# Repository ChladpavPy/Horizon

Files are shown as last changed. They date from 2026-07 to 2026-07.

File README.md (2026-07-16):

# Horizon
Custom Rocket Flight Controller

So first I want to explain, why I started this project. I have always wanted to build my own rocket, but for a long time it was just impossible and senseless. It is generally prohibited to fly with your own custom rockets, there was nowhere to safely test them, and it could be very dangerous. But then I noticed the ČVUT rocketry challenge, where it is actually possible to do it safely and legally.

I also thought about getting some friends or classmates to join this project, which is very likely to happen. We would probably work on the mechanical rocket body together, but I realized that a rocket without a computer is basically just a firework. So it was my idea to design and build my own custom flight computer for this rocket. I also designed the avionics bay to house the electronics.

I am still not exactly sure what the real specifications for this competition will be, because they will probably be published next year in February. But that is actually a big advantage. It means I will have plenty of time to test the flight computer thoroughly and gather a solid team to build the rest of the project. I already did all the hardware and computer work, so we are prepared to fly it.

You might notice that parts like the rocket engine, the main body tube, and the deployable parachute are not included in the bom. The parachute will be deployed by the pyro channels that I designed on the board, but these mechanical parts are missing from the BOM because they will very likely be funded and specified by the ČVUT competition with the proper dimensions. For the avionics bay, it does not really matter what the final dimensions are. Because it is just plastic, I can easily redesign it for different tube dimensions and 3D print it again.

## Project Features

* **Microcontroller:** STM32F405RGT6 (64-pin, 32-bit ARM Cortex-M4)
* **Stackup:** 4-Layer PCB for internal routing and better EMI shielding during flight
* **Sensors:** ICM-42688-P 6-axis IMU, ADXL372 high-g (200g) accelerometer for launch and impact detection, and dual barometers (BMP580 & MS5611) for precise altitude tracking
* **Telemetry:** LoRa E22-900M22S module for long-range real-time data transmission
* **Power:** 2S LiPo main input with high-efficiency TPS54525 step-down regulator
* **Data Logging:** Onboard W25Q128 128Mbit SPI Flash memory for high-speed flight data recording
* **Recovery System:** Dedicated pyro channels designed for reliable parachute deployment
* **Positioning:** Interface for high-precision external GPS (GEPRC GEP-M1025-DQ)

* And more other...

## Gallery

### 3D PCB Render
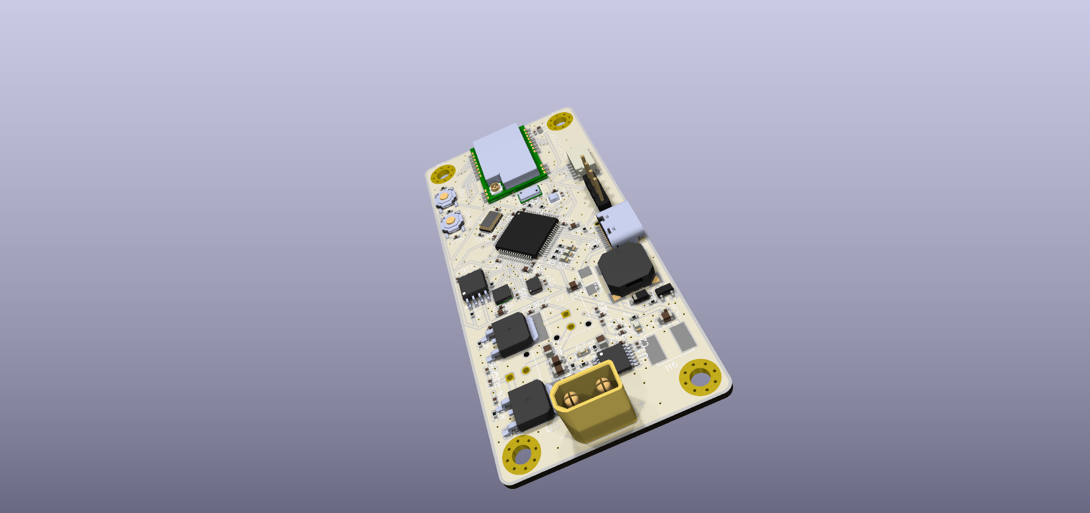
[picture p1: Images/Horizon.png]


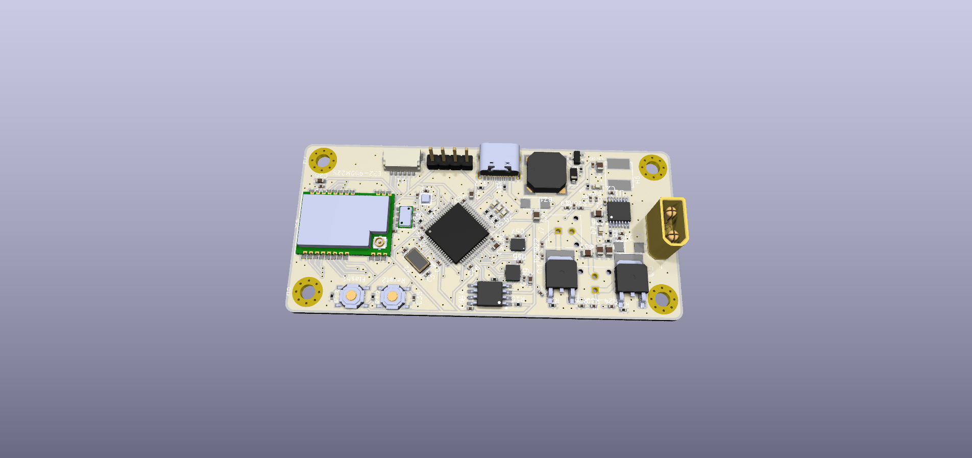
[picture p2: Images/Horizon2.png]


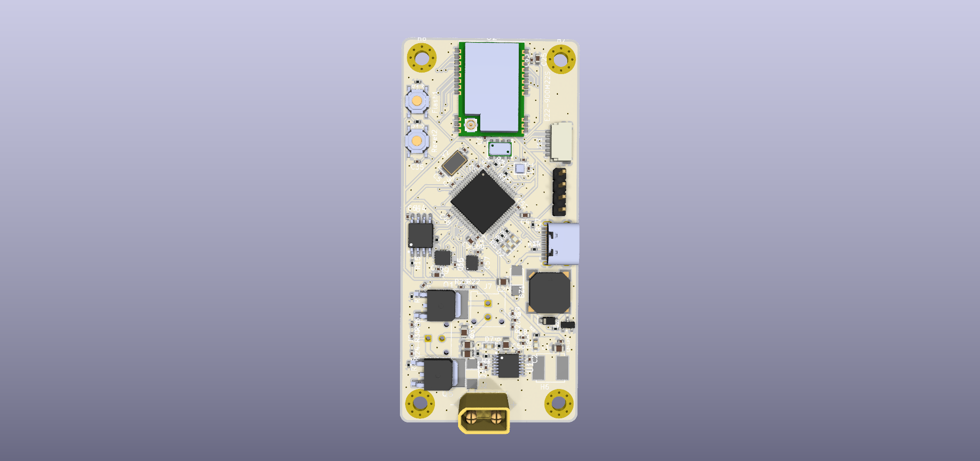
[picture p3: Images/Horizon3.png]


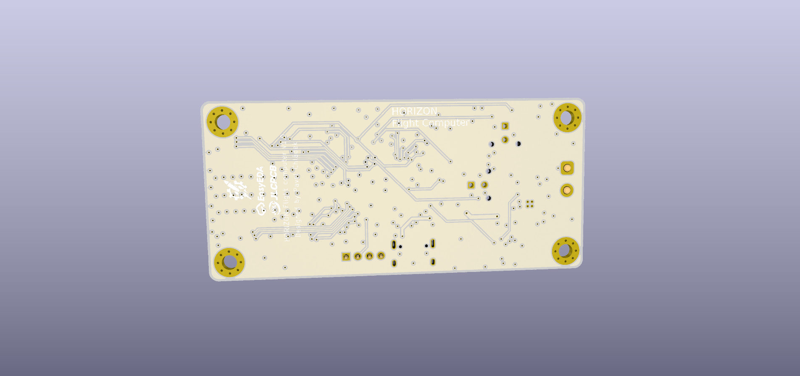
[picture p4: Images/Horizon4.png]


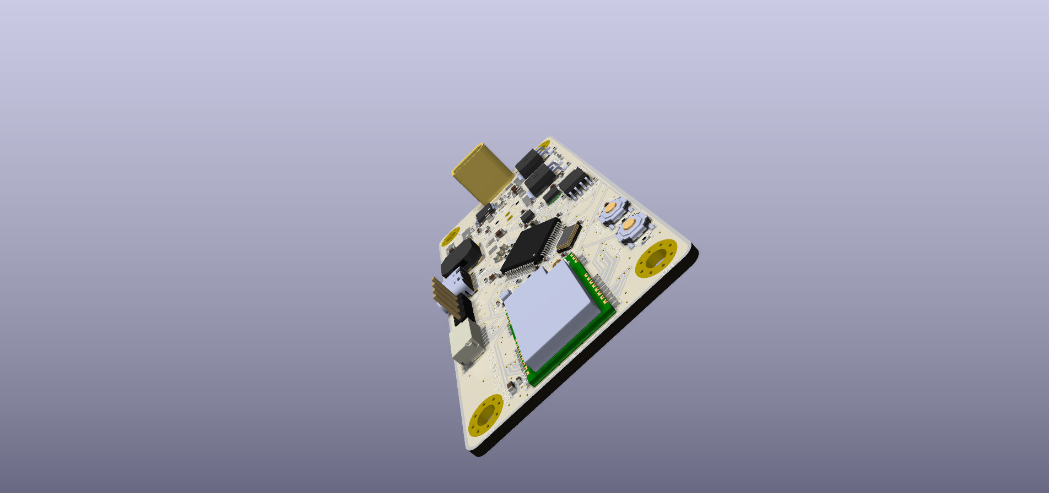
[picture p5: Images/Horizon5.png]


### PCB Routing
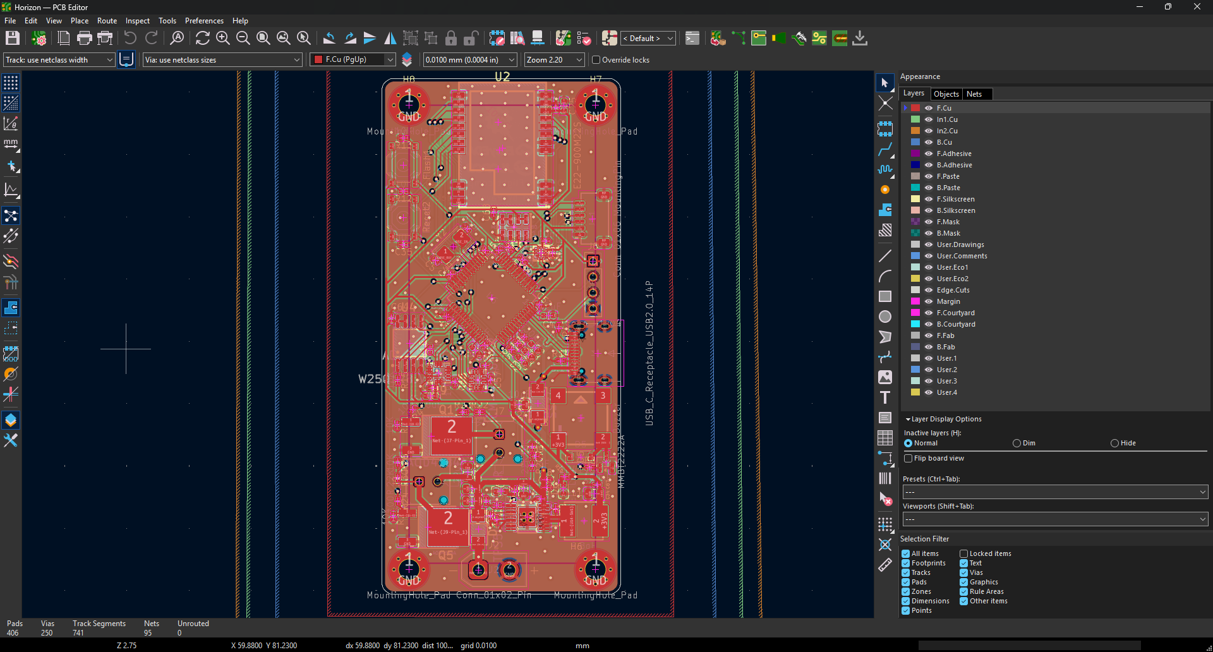
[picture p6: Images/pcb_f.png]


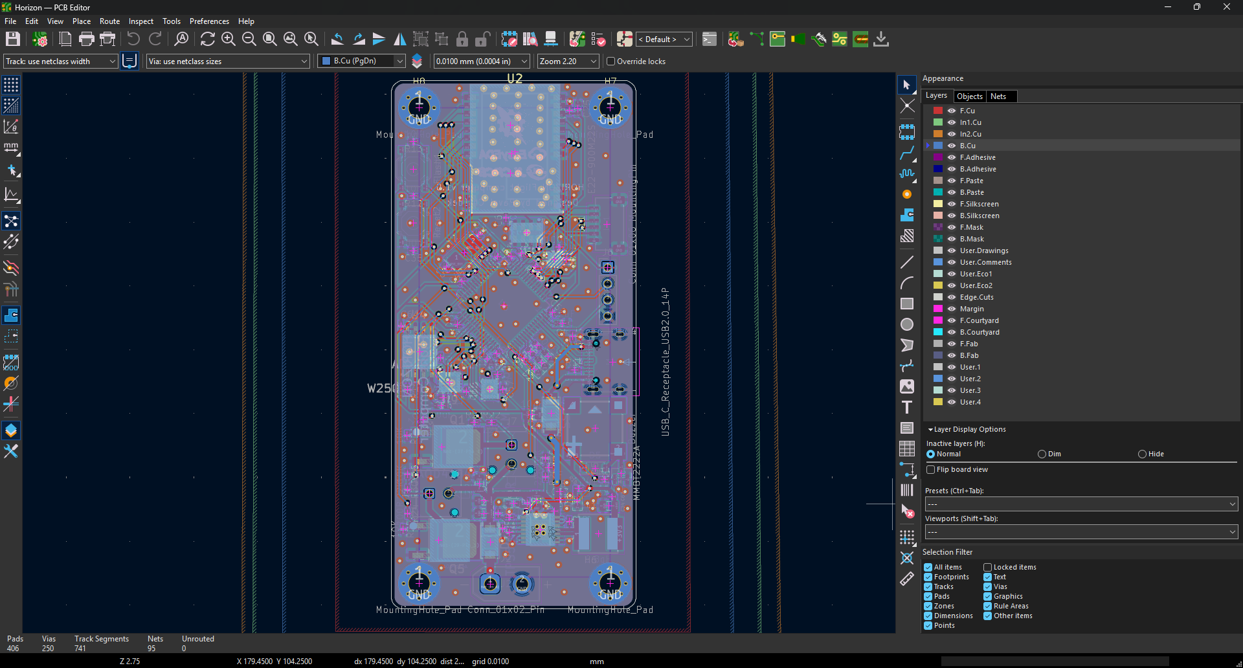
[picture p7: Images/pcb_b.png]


### Schematic
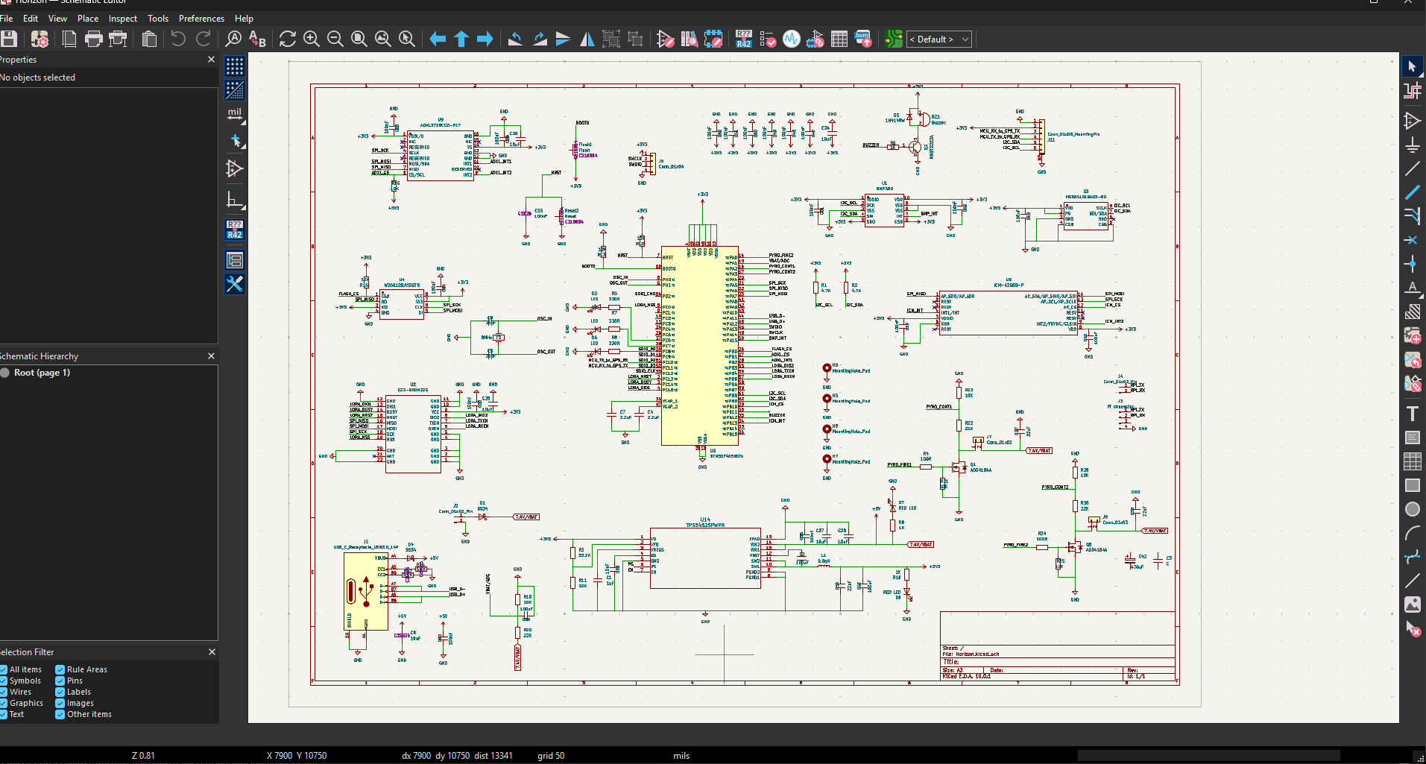
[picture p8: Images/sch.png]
Schematic


### Avionics Bay Assembly

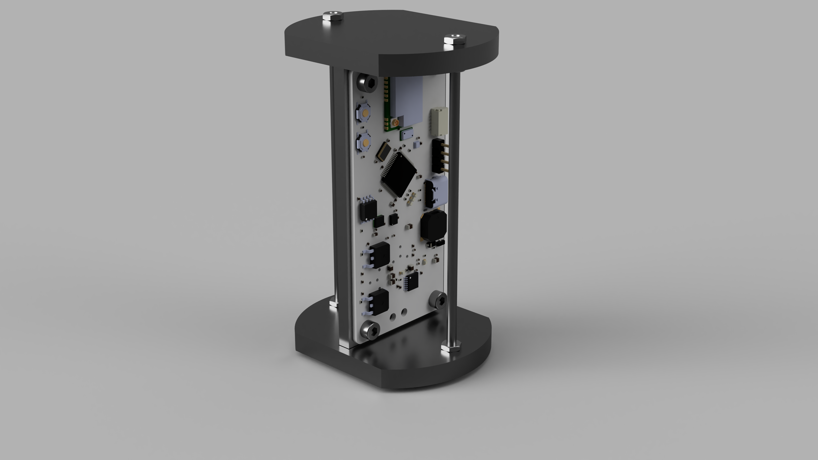
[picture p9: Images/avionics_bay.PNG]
Avionics Bay


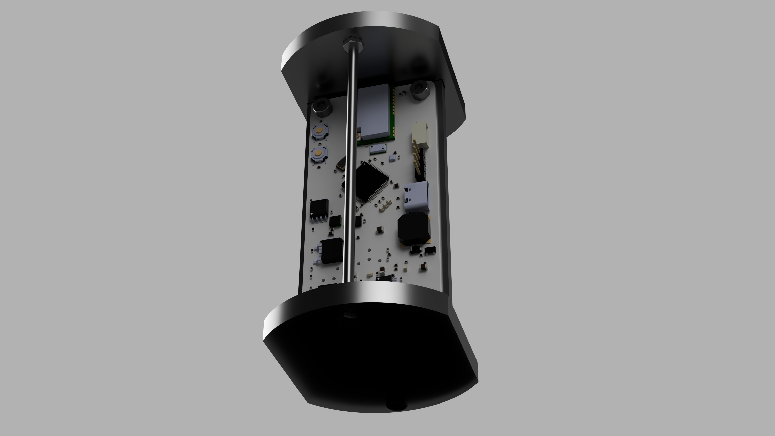
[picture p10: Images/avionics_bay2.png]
Avionics Bay


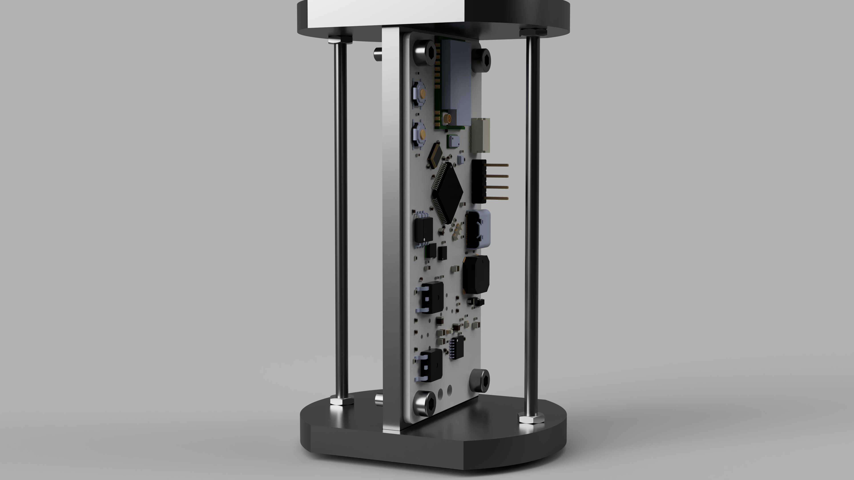
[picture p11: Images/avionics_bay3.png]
Avionics Bay


---

## Bill of Materials (BOM)

| Component | Qty | Purpose / Description | Price (USD) | Link / Distributor |
| :--- | :---: | :--- | :--- | :--- |
| **Custom PCB Manufacture** | 2 | The actual circuit board to solder everything on. Ordered via JLCPCB standard 4-layer service. | 209.53$ | [JLCPCB](https://jlcpcb.com) |
| **2S battery** | 1 | Power source / The whole pcb and pyros will get power from this. | 12.77$ | [Allegro](https://allegro.cz/produkt/akumulator-lipo-tattu-hv-550mah-2s-7-6v-xt30-dac8961b-6a7f-4425-9fd0-e271a79d3002?offerId=17837986320) |
| **HOTA D6 Pro Charger** | 1 | Dual-channel AC/DC LiPo charger for safe battery maintenance. Critical for preventing thermal runaway during 2S LiPo charging. Specifically chosen for its ability to accurately measure internal cell resistance (IR) to verify battery health for high-current pyro deployments, and its adjustable lab power supply mode for safely bringing up and testing the custom TPS step-down converters on the PCB without the risk of frying the new board. | $121.57 | [HobbyDrone.cz](https://www.hobbydrone.cz/cs/charger-hota-d6-pro-325w-15a-1-6s-dual-ac-dc/) |
| **GEPRC GEP-M1025-DQ GPS** | 1 | High-precision positioning data (u-blox M10) with integrated QMC5883L compass and backup DPS310 barometer. | $19.80 | [Banggood](https://www.banggood.com/cs/GEPRC-GEP-M1025-Series-M10-Chip-GPS-Module-for-RC-Drone-FPV-Racing-Helicopter-Quadcopter-RC-Airplane-Car-p-2000868.html?ID=6324596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) |

### Manual Assembly Components (LCSC.com)
*Note: Due to the high complexity and cost of standard PCBA services for LGA-type sensors, these components are ordered separately and will be manually reflow soldered using a stencil and hot plate.*

| Component | Qty | Purpose / Description | Price (USD) | LCSC Part # |
| :--- | :---: | :--- | :--- | :--- |
| **ADXL372BCCZ-RL7** | 2 | High-g accelerometer (200g) for impact detection. | 35.41$ | C579465 |
| **BMP580** | 5 | Precision barometric pressure sensor. | 5.96$ | C22391138 |
| **TPS54525PWPR** | 5 | High-efficiency buck regulator. | 5.24$ | C140350 |
| **Total LCSC Cost** | - | Including shipping | **50.46$** | - |

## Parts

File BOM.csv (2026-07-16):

Designator | Footprint | Quantity | Value | LCSC Part #
BZ1 | BUZ-SMD_4P-L8.5-W8.5-P8.50-TL | 1 | Buzzer | C95298
C1 | 0402 | 1 | 1uF | C52923
C2, C47, C48, C49, C50, C51, C52, C53, C56, C57, C59, C60, C61, C62, C63, C64, C65, C66, C67, C68 | 0402 | 20 | 100nF | C307331
C24, C27, C28 | 0805 | 3 | 10uF | C15850
C25, C26 | 0603 | 2 | 10uF | C19702
C34, C36, C37 | 0805 | 3 | 22uF | C45783
C35 | 0402 | 1 | 100nF | C1525
C4, C7 | 0603 | 2 | 2.2uF | C23630
C5, C6 | 0402 | 2 | 33pF | C1562
C58 | 0402 | 1 | 10nF | C15195
C8 | 0603 | 1 | 10uF | C96446
D1, D4 | SMA_L4.3-W2.6-LS5.2-RD | 2 | SS34 | C8678
D2, D7, D8 | 0603 | 3 | LED | C2286
D3 | 0603 | 1 | LED | C2288
D5 | D_SOD-123 | 1 | 1N4148W | C81598
D6 | 0603 | 1 | LED | C12624
FLASH1 | SW_Push_1P1T_XKB_TS-1187A | 1 | Flash | C318884
J1 | USB_C_Receptacle_HCTL_HC-TYPE-C-16P-01A | 1 | USB_C_Receptacle_USB2.0_14P | C19274016
J11 | JST_SH_SM06B-SRSS-TB_1x06-1MP_P1.00mm_Horizontal | 1 | Conn_01x06_MountingPin
J2 | AMASS_XT30UPB-M_1x02_P5.0mm_Vertical | 1 | Conn_01x02_Pin | C428721
J6 | PinHeader_1x04_P2.54mm_Vertical | 1 | Conn_01x04
J7, J9 | Molex_Micro-Fit_3.0_43045-0212_2x01_P3.00mm_Vertical | 2 | Conn_01x02
L1 | IND-SMD_L6.0-W6.0_SWPA6045S | 1 | 6.8qH | C57254
Q1, Q5 | TO-252-2_L6.6-W6.1-P4.57-LS9.9-TL-CW | 2 | AOD4184A | C99124
Q2 | SOT-23 | 1 | MMBT2222A | C8512
R1, R2 | 0402 | 2 | 4.7K | C25900
R10, R6, R9 | 0402 | 3 | 1K | C11702
R11, R25 | 0402 | 2 | 10K | C25804
R12, R13, R15, R16, R19, R21, R23, R26 | 0402 | 8 | 10K | C25744
R14, R17 | 0402 | 2 | 5.1K | C25905
R20, R22, R30 | 0402 | 3 | 22K | C25768
R24, R4 | 0402 | 2 | 100R | C25076
R3 | 0402 | 1 | 33.2K | C850963
R5, R7, R8 | 0402 | 3 | 330R | C25104
RESET2 | SW_Push_1P1T_XKB_TS-1187A | 1 | Reset | C318884
U1 | LGA-10_L2.0-W2.0-P0.50-TL_BMP580 | 1 | BMP580 | C22391138
U14 | TSSOP-14_L5.0-W4.4-P0.65-LS6.4-BL-EP | 1 | TPS54525PWPR | C140350
U2 | WIRELM-SMD_E22-900M22S | 1 | E22-900M22S | C411293
U3 | SENSORS-SMD_MS5611-01BA03 | 1 | MS561101BA03-50
U4 | SOIC-8_L5.3-W5.3-P1.27-LS8.0-BL | 1 | W25Q128JVSIQTR | C97521
U5 | LGA-14_L3.0-W2.5-P0.50-TL | 1 | ICM-42688-P | C1850418
U6 | LQFP-64_10x10mm_P0.5mm | 1 | STM32F405RGTx | C15742
U9 | LGA-16_L3.3-W3.0-P0.50-TL | 1 | ADXL372BCCZ-RL7 | C579465
Y2 | Crystal_SMD_5032-2Pin_5.0x3.2mm | 1 | 8MHz | C115962

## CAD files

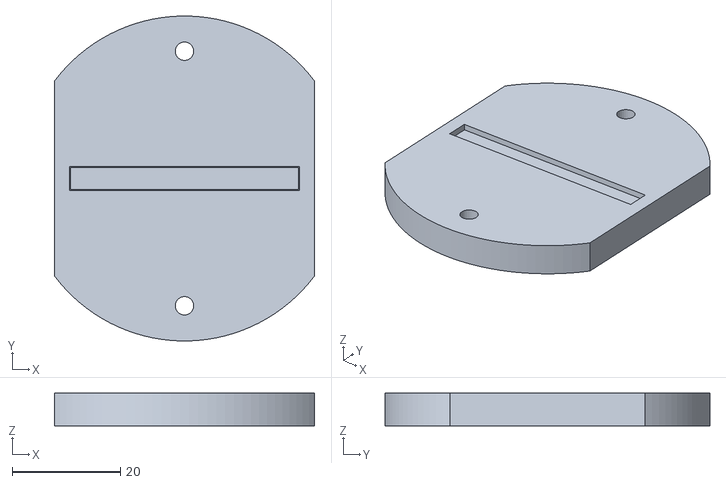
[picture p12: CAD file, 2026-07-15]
3D_Models/Bottom_Avionics_Bay.stl
48.0 x 60.0 x 6.00

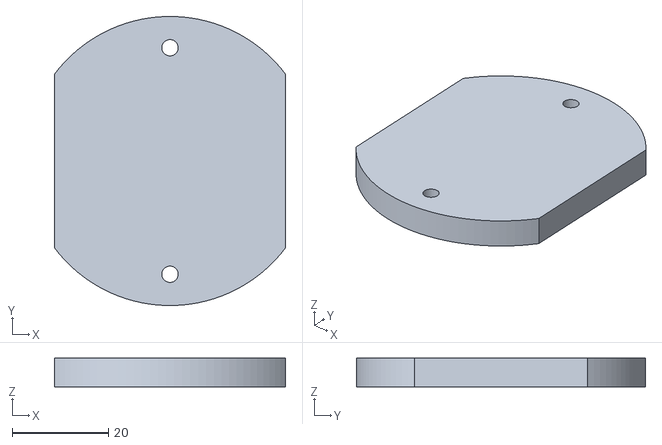
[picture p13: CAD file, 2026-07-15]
3D_Models/Upper_Avionics_Bay.stl
48.0 x 60.0 x 6.00

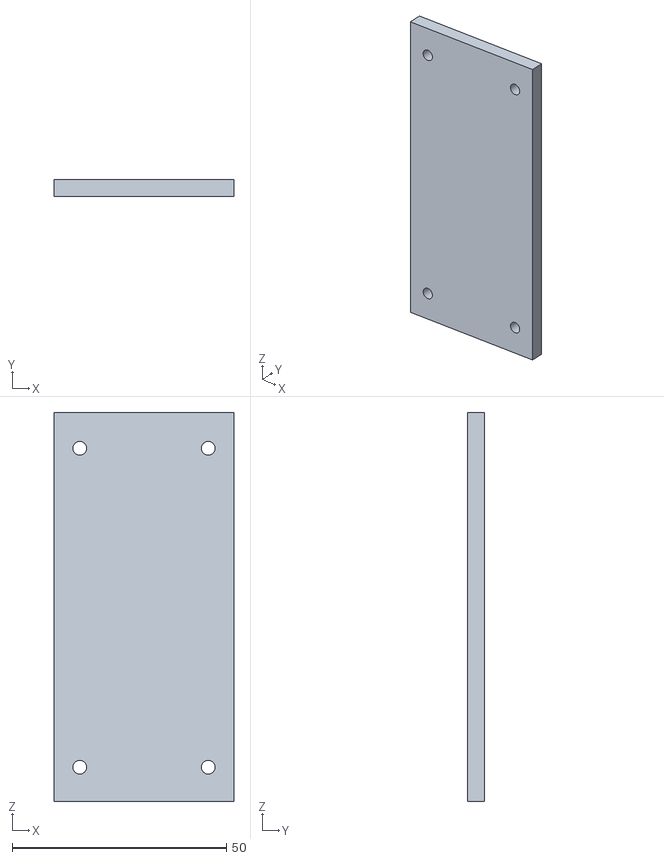
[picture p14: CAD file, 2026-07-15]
3D_Models/Avionics_Bay_Middle.stl
42.0 x 4.00 x 90.8

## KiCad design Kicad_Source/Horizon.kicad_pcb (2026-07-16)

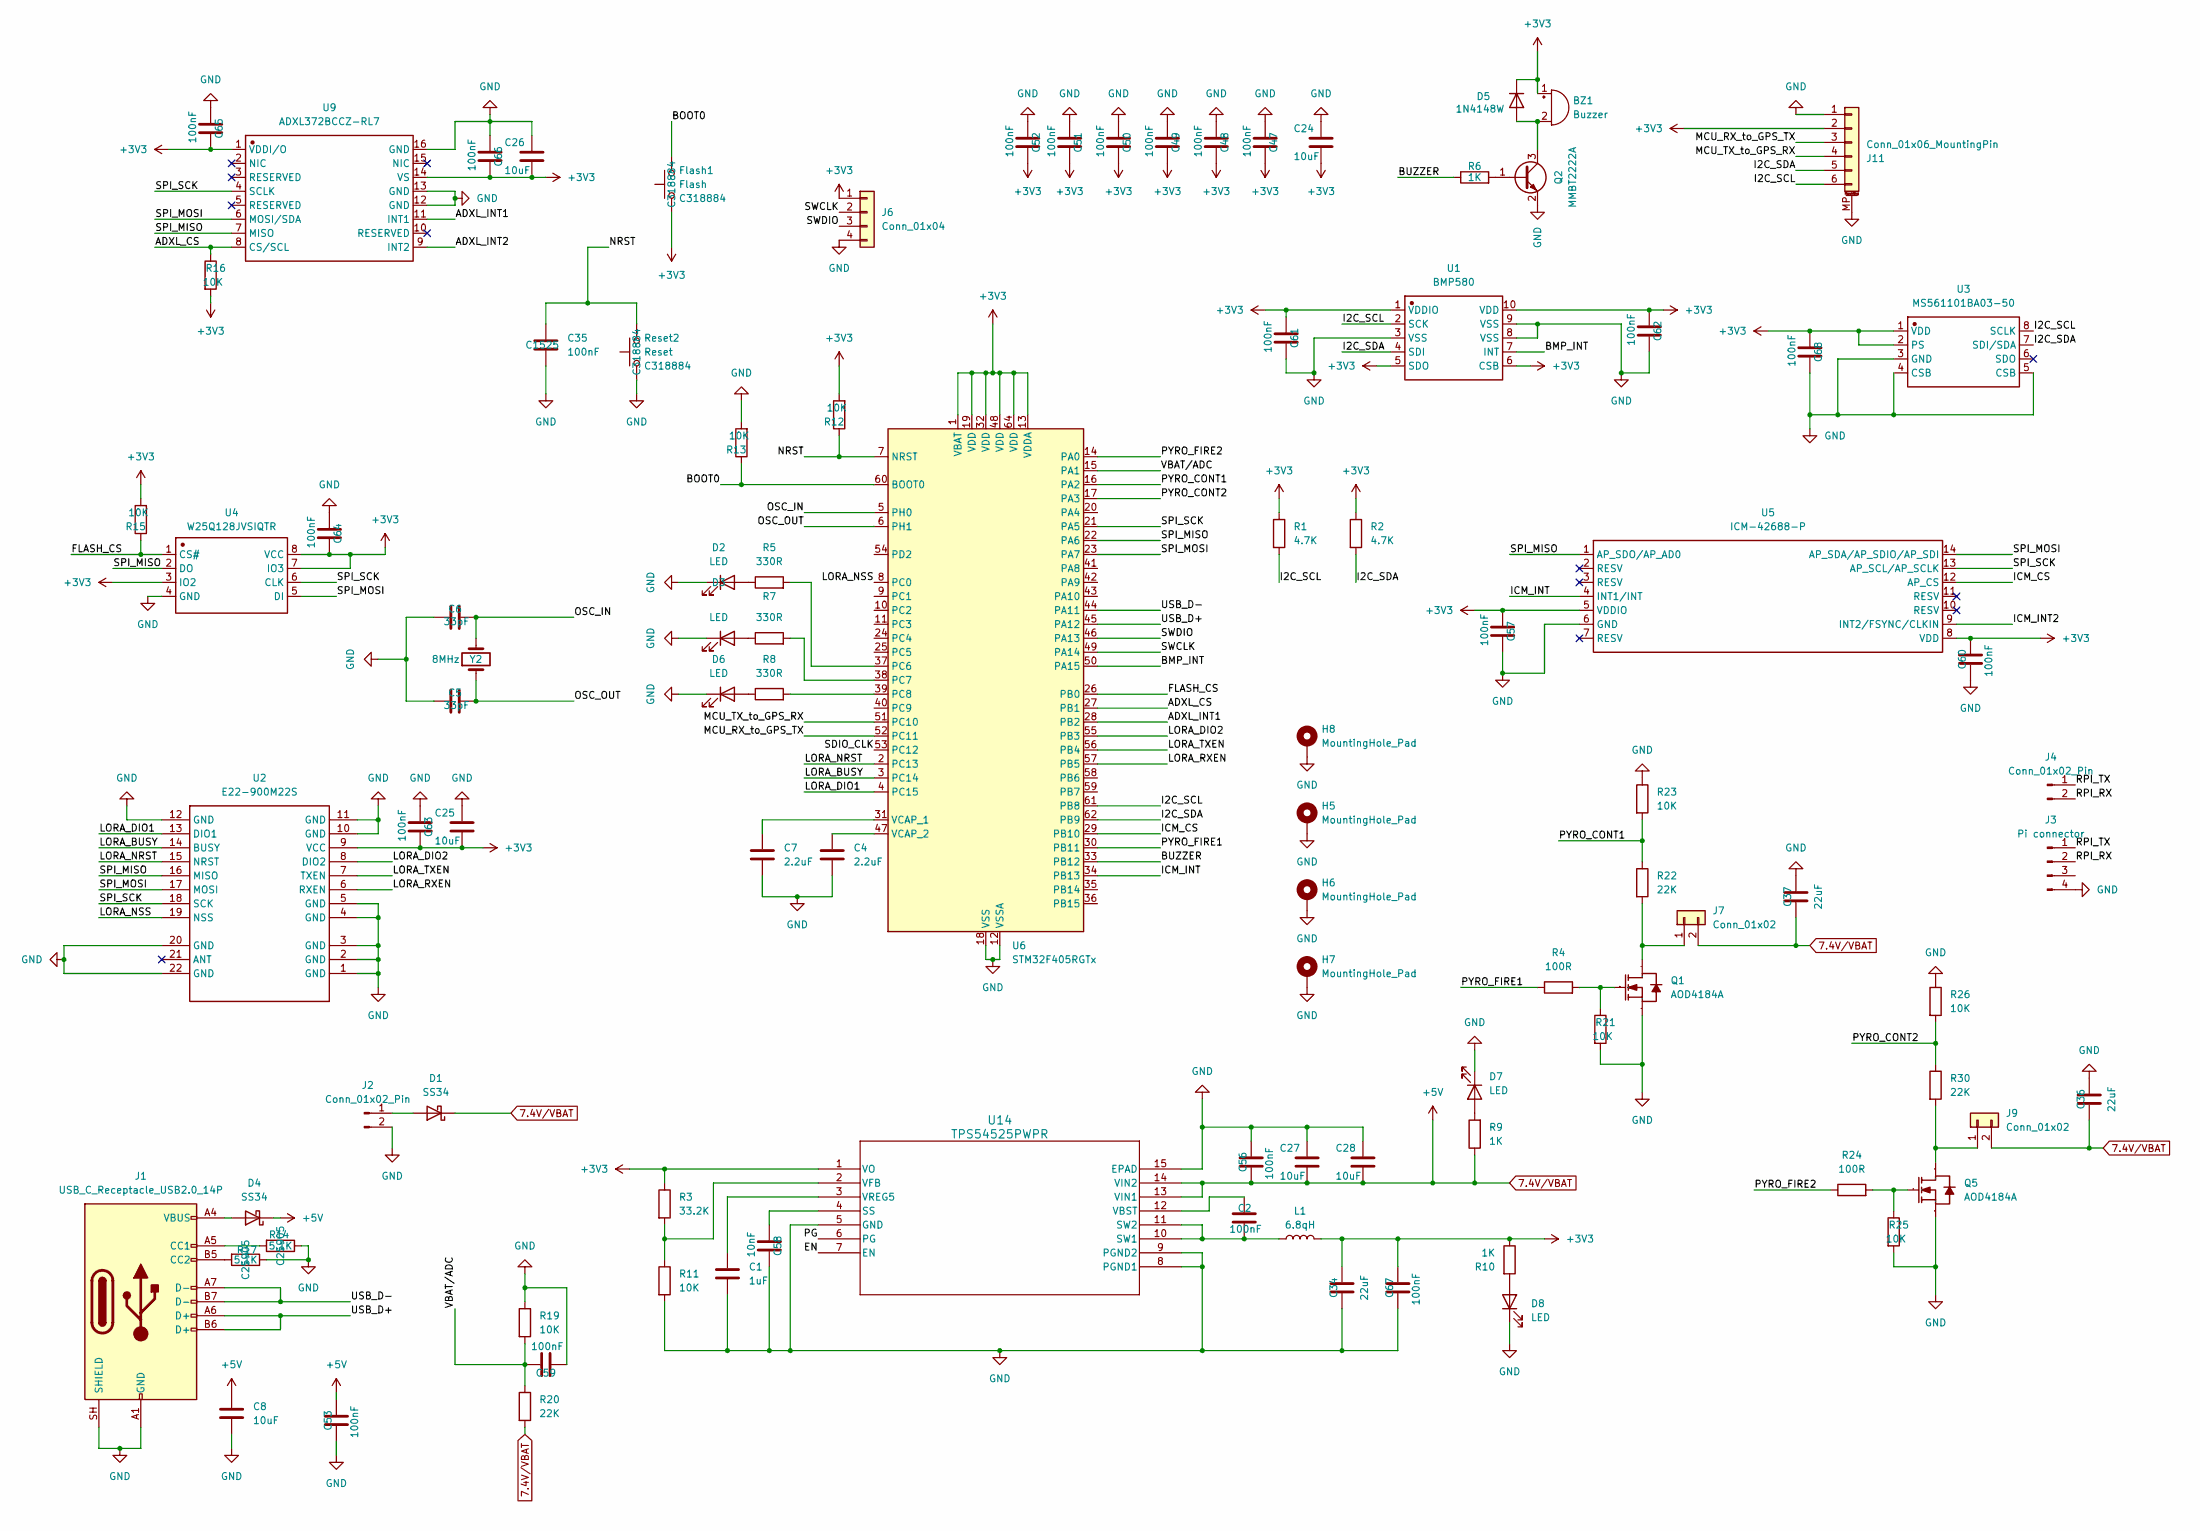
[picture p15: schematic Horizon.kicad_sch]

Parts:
BZ1: Buzzer; BUZ-SMD_4P-L8.5-W8.5-P8.50-TL; LCSC C95298
C1: 1uF; C_0402_1005Metric; LCSC C52923
C2, C47, C48, C49, C50, C51, C52, C53, C56, C57, C59, C60, C61, C62, C63, C64, C65, C66, C67, C68: 100nF; C_0402_1005Metric; LCSC C307331
C4, C7: 2.2uF; C_0603_1608Metric; LCSC C23630
C5, C6: 33pF; C_0402_1005Metric; LCSC C1562
C8: 10uF; C_0603_1608Metric; LCSC C96446
C24, C27, C28: 10uF; C_0805_2012Metric; MNF PART NUMBER C15850; LCSC C15850
C25, C26: 10uF; C_0603_1608Metric; MNF PART NUMBER C19702; LCSC C19702
C34, C36, C37: 22uF; C_0805_2012Metric; LCSC C45783
C35: 100nF; C_0402_1005Metric; MNF PART NUMBER C1525; LCSC C1525
C58: 10nF; C_0402_1005Metric; LCSC C15195
D1, D4: SS34; SMA_L4.3-W2.6-LS5.2-RD; LCSC C8678
D2, D7, D8: LED; LED_0603_1608Metric; LCSC C2286
D3: LED; LED_0603_1608Metric; LCSC C2288
D5: 1N4148W; D_SOD-123; LCSC C81598
D6: LED; LED_0603_1608Metric; LCSC C12624
Flash1: Flash; SW_Push_1P1T_XKB_TS-1187A; MNF PART NUMBER C318884; LCSC C318884
H5, H6, H7, H8: MountingHole_Pad; MountingHole_3.2mm_M3_Pad_Via
J1: USB_C_Receptacle_USB2.0_14P; USB_C_Receptacle_HCTL_HC-TYPE-C-16P-01A; LCSC C19274016
J2: Conn_01x02_Pin; AMASS_XT30UPB-M_1x02_P5.0mm_Vertical; LCSC C428721
J3: Pi connector
J4: Conn_01x02_Pin
J6: Conn_01x04; PinHeader_1x04_P2.54mm_Vertical
J7, J9: Conn_01x02; Molex_Micro-Fit_3.0_43045-0212_2x01_P3.00mm_Vertical
J11: Conn_01x06_MountingPin; JST_SH_SM06B-SRSS-TB_1x06-1MP_P1.00mm_Horizontal
L1: 6.8qH; IND-SMD_L6.0-W6.0_SWPA6045S; LCSC C57254
Q1, Q5: AOD4184A; TO-252-2_L6.6-W6.1-P4.57-LS9.9-TL-CW; Manufacturer Part AOD4184A; LCSC C99124
Q2: MMBT2222A; SOT-23; LCSC C8512
R1, R2: 4.7K; R_0402_1005Metric; LCSC C25900
R3: 33.2K; R_0402_1005Metric; LCSC C850963
R4, R24: 100R; C_0402_1005Metric; LCSC C25076
R5, R7, R8: 330R; R_0402_1005Metric; LCSC C25104
R6, R9, R10: 1K; R_0402_1005Metric; LCSC C11702
R11, R25: 10K; R_0402_1005Metric; LCSC C25804
R12, R13, R15, R16, R21: 10K; R_0402_1005Metric; LCSC C25744
R14, R17: 5.1K; R_0402_1005Metric; MNF PART NUMBER C25905; LCSC C25905
R19, R23, R26: 10K; C_0402_1005Metric; LCSC C25744
R20, R22, R30: 22K; C_0402_1005Metric; LCSC C25768
Reset2: Reset; SW_Push_1P1T_XKB_TS-1187A; MNF PART NUMBER C318884; LCSC C318884
U1: BMP580; LGA-10_L2.0-W2.0-P0.50-TL_BMP580; Manufacturer Part BMP580; LCSC C22391138
U2: E22-900M22S; WIRELM-SMD_E22-900M22S; Manufacturer Part E22-900M22S; LCSC C411293
U3: MS561101BA03-50; SENSORS-SMD_MS5611-01BA03; Manufacturer Part MS561101BA03-50
U4: W25Q128JVSIQTR; SOIC-8_L5.3-W5.3-P1.27-LS8.0-BL; Manufacturer Part W25Q128JVSIQ; LCSC C97521
U5: ICM-42688-P; LGA-14_L3.0-W2.5-P0.50-TL; Manufacturer Part ICM-42688-P; LCSC C1850418
U6: STM32F405RGTx; LQFP-64_10x10mm_P0.5mm; LCSC C15742
U9: ADXL372BCCZ-RL7; LGA-16_L3.3-W3.0-P0.50-TL; Manufacturer Part ADXL372BCCZ-RL7; LCSC C579465
U14: TPS54525PWPR; TSSOP-14_L5.0-W4.4-P0.65-LS6.4-BL-EP; LCSC C140350
Y2: 8MHz; Crystal_SMD_5032-2Pin_5.0x3.2mm; LCSC C115962

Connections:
7.4V/VBAT: C8.1, C27.2, C28.2, C36.2, C37.2, C53.1, C56.2, D1.1 (K), D4.1 (K), J7.2, J9.2, R9.1, R20.2, U14.13 (VIN1), U14.14 (VIN2)
+3V3: BZ1.1 (+), C24.2, C25.2, C26.2, C34.1, C47.1, C48.1, C49.1, C50.1, C51.1, C52.1, C57.2, C60.1, C61.2, C62.2, C63.1, C64.1, C65.1, C66.1, C67.1, C68.2, D5.1 (K), Flash1.1, J6.1, J11.2, L1.2, R1.1, R2.1, R3.1, R10.1, R12.2, R15.2, R16.2, U1.1 (VDDIO), U1.5 (SDO), U1.6 (CSB), U1.10 (VDD), U2.9 (VCC), U3.1 (VDD), U3.2 (PS), U4.3 (IO2), U4.7 (IO3), U4.8 (VCC), U5.5 (VDDIO), U5.8 (VDD), U6.1 (VBAT), U6.13 (VDDA), U6.19 (VDD), U6.32 (VDD), U6.48 (VDD), U6.64 (VDD), U9.1 (VDDI/O), U9.14 (VS), U14.1 (VO)
/ADXL_CS: R16.1, U6.27 (PB1), U9.8 (CS/SCL)
/ADXL_INT1: U6.28 (PB2), U9.11 (INT1)
/ADXL_INT2: U9.9 (INT2)
/BMP_INT: U1.7 (INT), U6.50 (PA15)
/BOOT0: Flash1.2, R13.1, U6.60 (BOOT0)
/BUZZER: R6.1, U6.33 (PB12)
/EN: U14.7 (EN)
/FLASH_CS: R15.1, U4.1 (CS#), U6.26 (PB0)
/I2C_SCL: J11.6, R1.2, U1.2 (SCK), U3.8 (SCLK), U6.61 (PB8)
/I2C_SDA: J11.5, R2.2, U1.4 (SDI), U3.7 (SDI/SDA), U6.62 (PB9)
/ICM_CS: U5.12 (AP_CS), U6.29 (PB10)
/ICM_INT: U5.4 (INT1/INT), U6.34 (PB13)
/ICM_INT2: U5.9 (INT2/FSYNC/CLKIN)
/LORA_BUSY: U2.14 (BUSY), U6.3 (PC14)
/LORA_DIO1: U2.13 (DIO1), U6.4 (PC15)
/LORA_DIO2: U2.8 (DIO2), U6.55 (PB3)
/LORA_NRST: U2.15 (NRST), U6.2 (PC13)
/LORA_NSS: U2.19 (NSS), U6.8 (PC0)
/LORA_RXEN: U2.6 (RXEN), U6.57 (PB5)
/LORA_TXEN: U2.7 (TXEN), U6.56 (PB4)
/MCU_RX_to_GPS_TX: J11.3, U6.52 (PC11)
/MCU_TX_to_GPS_RX: J11.4, U6.51 (PC10)
/NRST: C35.1, R12.1, Reset2.2, U6.7 (NRST)
/OSC_IN: C6.1, U6.5 (PH0), Y2.2
/OSC_OUT: C5.1, U6.6 (PH1), Y2.1
/PG: U14.6 (PG)
/PYRO_CONT1: R22.1, R23.2, U6.16 (PA2)
/PYRO_CONT2: R26.2, R30.1, U6.17 (PA3)
/PYRO_FIRE1: R4.1, U6.30 (PB11)
/PYRO_FIRE2: R24.1, U6.14 (PA0)
/SDIO_CLK: U6.53 (PC12)
/SPI_MISO: U2.16 (MISO), U4.2 (DO), U5.1 (AP_SDO/AP_AD0), U6.22 (PA6), U9.7 (MISO)
/SPI_MOSI: U2.17 (MOSI), U4.5 (DI), U5.14 (AP_SDA/AP_SDIO/AP_SDI), U6.23 (PA7), U9.6 (MOSI/SDA)
/SPI_SCK: U2.18 (SCK), U4.6 (CLK), U5.13 (AP_SCL/AP_SCLK), U6.21 (PA5), U9.4 (SCLK)
/SWCLK: J6.2, U6.49 (PA14)
/SWDIO: J6.3, U6.46 (PA13)
/USB_D+: J1.A6 (D+), J1.B6 (D+), U6.45 (PA12)
/USB_D-: J1.A7 (D-), J1.B7 (D-), U6.44 (PA11)
/VBAT/ADC: C59.1, R19.2, R20.1, U6.15 (PA1)
GND: C1.2, C4.1, C5.2, C6.2, C7.1, C8.2, C24.1, C25.1, C26.1, C27.1, C28.1, C34.2, C35.2, C36.1, C37.1, C47.2, C48.2, C49.2, C50.2, C51.2, C52.2, C53.2, C56.1, C57.1, C58.1, C59.2, C60.2, C61.1, C62.1, C63.2, C64.2, C65.2, C66.2, C67.2, C68.1, D2.1 (K), D3.1 (K), D6.1 (K), D7.1 (K), D8.1 (K), H5.1 (1_1), H6.1 (1_1), H7.1 (1_1), H8.1 (1_1), J1.A1 (GND), J1.A12 (GND), J1.B1 (GND), J1.B12 (GND), J1.SH (SHIELD), J2.2, J3.4, J6.4, J11.1, J11.MP (MountPin), Q1.3 (S), Q2.2 (E), Q5.3 (S), R11.2, R13.2, R14.1, R17.1, R19.1, R21.2, R23.1, R25.2, R26.1, Reset2.1, U1.3 (VSS), U1.8 (VSS), U1.9 (VSS), U2.1 (GND), U2.2 (GND), U2.3 (GND), U2.4 (GND), U2.5 (GND), U2.10 (GND), U2.11 (GND), U2.12 (GND), U2.20 (GND), U2.22 (GND), U3.3 (GND), U3.4 (CSB), U3.5 (CSB), U4.4 (GND), U5.6 (GND), U6.12 (VSSA), U6.18 (VSS), U6.63 (VSS), U9.12 (GND), U9.13 (GND), U9.16 (GND), U14.5 (GND), U14.8 (PGND1), U14.9 (PGND2), U14.15 (EPAD)
unnamed: BZ1.2 (-), D5.2 (A), Q2.3 (C)
unnamed: D1.2 (A), J2.1
unnamed: D2.2 (A), R5.1
unnamed: D3.2 (A), R7.1
unnamed: D4.2 (A), J1.A4 (VBUS), J1.A9 (VBUS), J1.B4 (VBUS), J1.B9 (VBUS)
unnamed: D6.2 (A), R8.1
unnamed: D7.2 (A), R9.2
unnamed: D8.2 (A), R10.2
unnamed: J1.A5 (CC1), R14.2
unnamed: J1.B5 (CC2), R17.2
unnamed: J3.1, J4.1
unnamed: J3.2, J4.2
unnamed: J7.1, Q1.2 (D), R22.2
unnamed: J9.1, Q5.2 (D), R30.2
unnamed: Q1.1 (G), R4.2, R21.1
unnamed: Q2.1 (B), R6.2
unnamed: Q5.1 (G), R24.2, R25.1
unnamed: R5.2, U6.37 (PC6)
unnamed: R7.2, U6.38 (PC7)
unnamed: R8.2, U6.39 (PC8)
unnamed: C7.2, U6.31 (VCAP_1)
unnamed: C4.2, U6.47 (VCAP_2)
unnamed: C58.2, U14.4 (SS)
unnamed: C2.2, L1.1, U14.10 (SW1), U14.11 (SW2)
unnamed: C2.1, U14.12 (VBST)
unnamed: R3.2, R11.1, U14.2 (VFB)
unnamed: C1.1, U14.3 (VREG5)

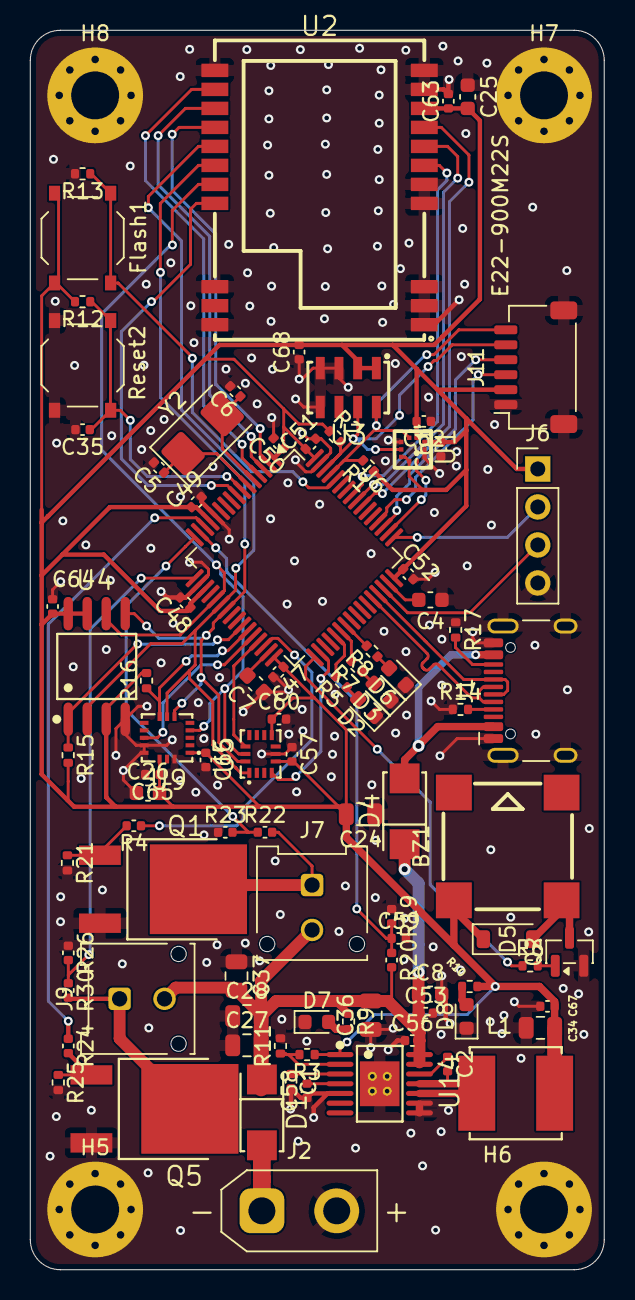
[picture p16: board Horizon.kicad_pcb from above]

Board: 4 copper layers, 38.4 x 82.8 mm, 96 parts (0 on the bottom side), 62 nets.

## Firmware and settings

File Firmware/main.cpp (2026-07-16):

#include "Arduino.h"

#define LORA_TXEN_PIN       4
#define LORA_TXEN_PORT      GPIOB

#define LORA_RXEN_PIN       5
#define LORA_RXEN_PORT      GPIOB

#define PYRO_FIRE1_PORT     GPIOB
#define PYRO_FIRE1_PIN      11

#define PYRO_FIRE2_PORT     GPIOA
#define PYRO_FIRE2_PIN      0

#define PYRO_CONT1_PORT     GPIOA
#define PYRO_CONT1_PIN      2

#define PYRO_CONT2_PORT     GPIOA
#define PYRO_CONT2_PIN      3

#define VBAT_ADC_PORT       GPIOA
#define VBAT_ADC_PIN        1

#define SPI_SCK_PORT        GPIOA
#define SPI_SCK_PIN         5

#define SPI_MISO_PORT       GPIOA
#define SPI_MISO_PIN        6

#define SPI_MOSI_PORT       GPIOA
#define SPI_MOSI_PIN        7

#define FLASH_CS_PORT       GPIOB
#define FLASH_CS_PIN        0

#define ADXL_CS_PORT        GPIOB
#define ADXL_CS_PIN         1

#define ADXL_INT1_PORT      GPIOB
#define ADXL_INT1_PIN       2

#define LORA_DIO2_PORT      GPIOB
#define LORA_DIO2_PIN       3

#define LORA_NSS_PORT       GPIOA
#define LORA_NSS_PIN        8

#define LORA_NRST_PORT      GPIOC
#define LORA_NRST_PIN       12

#define LORA_BUSY_PORT      GPIOC
#define LORA_BUSY_PIN       13

#define LORA_DIO1_PORT      GPIOC
#define LORA_DIO1_PIN       14

#define I2C_SCL_PORT        GPIOB
#define I2C_SCL_PIN         8

#define I2C_SDA_PORT        GPIOB
#define I2C_SDA_PIN         9

#define ICM_CS_PORT         GPIOB
#define ICM_CS_PIN          10

#define BUZZER_PORT         GPIOB
#define BUZZER_PIN          12

#define ICM_INT_PORT        GPIOB
#define ICM_INT_PIN         13

#define BMP_INT_PORT        GPIOA
#define BMP_INT_PIN         15

#define USB_DM_PORT         GPIOA
#define USB_DM_PIN          11

#define USB_DP_PORT         GPIOA
#define USB_DP_PIN          12

void setup() {
  Serial.begin(115200);
  delay(2000);

  Serial.println("Project Horizon");
  Serial.println("Flight Computer Booting...");

  pinMode(BUZZER_PIN, OUTPUT);
  
  pinMode(PYRO_CONT1_PIN, INPUT_PULLDOWN);
  pinMode(PYRO_CONT2_PIN, INPUT_PULLDOWN);

  digitalWrite(BUZZER_PIN, HIGH);
  delay(150);
  digitalWrite(BUZZER_PIN, LOW);
  delay(100);
  digitalWrite(BUZZER_PIN, HIGH);
  delay(150);
  digitalWrite(BUZZER_PIN, LOW);

  Serial.println("Hardware IO test completed. System Ready.");
}

void loop() {
  bool pyro1_cont = digitalRead(PYRO_CONT1_PIN);
  bool pyro2_cont = digitalRead(PYRO_CONT2_PIN);

  Serial.print("Status: STANDBY | ");
  Serial.print("Pyro 1 Cont: ");
  Serial.print(pyro1_cont ? "OK" : "FAIL");
  Serial.print(" | Pyro 2 Cont: ");
  Serial.println(pyro2_cont ? "OK" : "FAIL");

  delay(1000);
}

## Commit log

2026-07-06 Add Bill of Materials section to README
    Added a Bill of Materials (BOM) section with components, quantities, descriptions, and links.
2026-07-06 Update power delivery component details in README
2026-07-14 Revise Bill of Materials in README.md
    Updated the Bill of Materials section with new components and descriptions, including manual assembly components from LCSC.
2026-07-14 Revise section title to 'Manual Assembly Components (LCSC.com)'
    Updated the title of the Manual Assembly Components section to include the full LCSC.com name.
2026-07-14 Update charger information in README.md
2026-07-14 Change quantity of Custom PCB Manufacture in BOM
    Updated the quantity of Custom PCB Manufacture from 5 to 2.
2026-07-14 Update HOTA D6 Pro Charger price in README
    Updated price for HOTA D6 Pro Charger from ~$110 to 121,57$.
2026-07-15 Update price for Custom PCB Manufacture in BOM
    Updated the price for the Custom PCB Manufacture component in the Bill of Materials.
2026-07-15 Add project features to README
    Added project features section detailing microcontroller, PCB stackup, sensors, telemetry, power, data logging, recovery system, and positioning.
2026-07-15 Update safety description for HOTA D6 Pro Charger
    Clarified safety information regarding the HOTA D6 Pro Charger to emphasize prevention of battery hazards.
2026-07-15 Refine HOTA D6 Pro Charger description in README
    Updated the description of the HOTA D6 Pro Charger to emphasize safety and critical functions for battery management.
2026-07-15 Add gallery section with images to README
    Added a gallery section with images for PCB renders, routing, schematic, and avionics bay assembly.
2026-07-16 Revise HOTA D6 Pro Charger description in README
    Updated the description for the HOTA D6 Pro Charger to emphasize its importance in battery maintenance and safety during charging, including its features for measuring battery health and testing cust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
2026-07-16 Adjust price for ADXL372BCCZ-RL7 component
    Updated the price of the ADXL372BCCZ-RL7 accelerometer in the components list.
